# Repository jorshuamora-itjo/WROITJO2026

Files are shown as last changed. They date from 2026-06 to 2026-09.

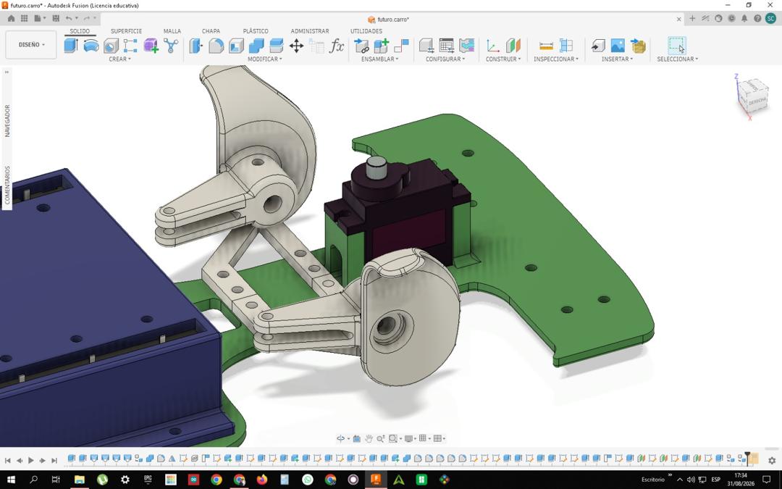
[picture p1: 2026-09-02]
photos/assembly_process/WhatsApp Image 2026-09-02 at 2.11.04 AM (2).jpeg

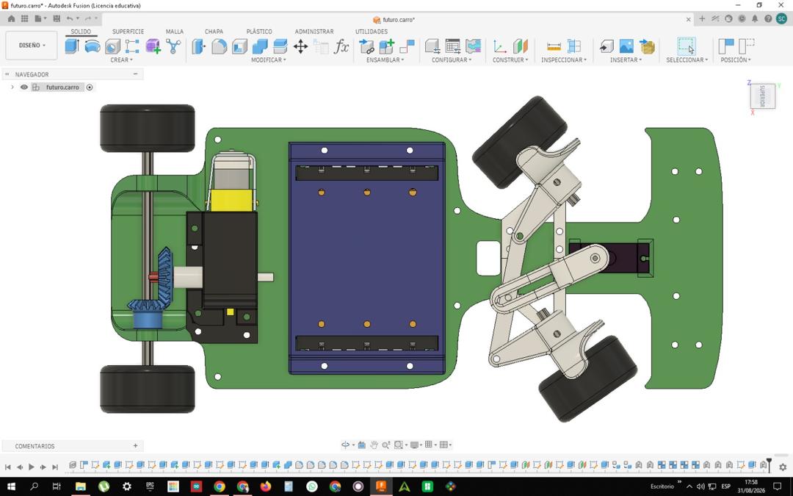
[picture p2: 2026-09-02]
photos/assembly_process/WhatsApp Image 2026-09-02 at 2.11.29 AM (2).jpeg

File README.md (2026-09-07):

<div align="center">

# WRO 2026 — Future Engineers
### **Team:** The Pits JO &nbsp;|&nbsp; **Robot:** Meteoro
**Instituto Técnico Jesús Obrero (ITJO)**






---

> 🇪🇸 **Nota para jueces y evaluadores en español:** Puedes leer la versión oficial traducida al español directamente en [`README_ES.md`](https://github.com/jorshuamora-itjo/WROITJO2026/blob/main/README.md#wro-2026--futuros-ingenieros).

---

</div>

## Engineering Materials

This repository contains all engineering materials, CAD models, schematic diagrams, source code, and technical documentation for the **Meteoro** autonomous vehicle, developed by team **The Pits JO** from **Jesús Obrero Technical Institute (ITJO)** for the **WRO Future Engineers 2026** competition.

### Repository Contents

* **[`README.md`](https://github.com/jorshuamora-itjo/WROITJO2026/blob/main/README.md#wro-2026--future-engineers)**: Main technical documentation in English.
* **[`README_ES.md`](https://github.com/jorshuamora-itjo/WROITJO2026/blob/main/README.md#wro-2026--futuros-ingenieros)**: Full technical documentation in Spanish.
* **[`LICENSE`](LICENSE)**: MIT open-source license corresponding to team The Pits JO.
* **[`.gitignore`](.gitignore)**: Configuration file to ignore build binaries and temporary files.
* **[`src/`](src/)**: Control software code for all components programmed for the competition.
* **[`models/`](models/)**: Files for models used by 3D printers, laser cutters, and CNC machines to manufacture vehicle parts.
* **[`photos/`](photos/)**: Unified photo gallery containing official team photos, vehicle views, and assembly/programming logs.
* **[`video/`](video/)**: File containing the direct link to the track demonstration video.
* **[`schematics/`](schematics/)**: Schematic diagrams of electromechanical components, illustrating all parts (electronic components and motors) used in the vehicle and how they connect.
* **[`docs/`](docs/)**: Additional documentation, datasheets, flow charts, and pit checklists.

---

> **Technical Nomenclature Clarification**
> 
> To facilitate reading the documentation and avoid confusion throughout this project, we use the following standard:
> 1. **Pit Dinoco (Version 1.1):** Our first experimental car. With it, we learned the fundamentals of the competition and identified the main flaws to correct.
> 2. **Meteoro (Version 2.0):** The definitive competition vehicle. It stems from a complete redesign of the mechanical structure, power circuits, and control software.

---

## Visual Comparison of Prototypes

| Design Criterion | Pit Dinoco ($v1.1$) | Meteoro ($v2.0$) |
| :--- | :--- | :--- |
| **Structure** | Single deck (monolayer) with exposed cables. | Double-deck modular chassis with internal cable routing channels. |
| **Steering** | Simple steering with servo exposed to wear. | Ackermann geometry with a Scotch Yoke mechanism. |
| **Drivetrain** | Visible spur gears. | Longitudinal motor with 90° bevel gears. |
| **Weight Distribution** | Batteries in the rear (caused understeer). | Batteries at the center of the lower chassis (50/50 balance). |
| **Distance Sensors** | HC-SR04 modules glued to the front. | RCWL-1601 sensors integrated inside the F1 front wing. |

---

## Introduction

The team **The Pits JO** consists of 6th-year Technical High School students from **Instituto Técnico Jesús Obrero (ITJO)**. Our academic background covers the fields of Electronics and Telematics, which provided us with the necessary tools to build an autonomous car from scratch.

Although in daily workshop practice we apply the philosophy of *"everyone does everything"* (assembling, soldering, programming, and track testing), we distribute primary responsibilities according to each member's specialty:

| Team Member | Academic Major | Primary Roles | Key Contributions and Cross-Functional Tasks |
| :--- | :--- | :--- | :--- |
| **Samuel Castillo** | Industrial Professional Technician in Electronics | 3D Mechanical Designer, Maintenance, and Electromechanical Integration | Designed the 3D parts and chassis for the  $v1.1$  and  $v2.0$  prototypes, calibrated the steering system, manufactured custom gears, and supported motor testing routines. |
| **Jorshua Mora** | Industrial Professional Technician in Telematics | Lead Software Programmer, Vision Specialist, and Pit Crew | Developed the core code, configured the PixyCam2 vision sensor, managed rapid maintenance in the competition pit area, and assisted with wiring harness assembly. |
| **Winston Garrido** | Industrial Professional Technician in Electronics | PID Control Algorithms, Schematic Designer, and Repository Manager | Calibrated the $PD$ trajectory control system, designed the power distribution network, drew schematic diagrams, and organized all technical documentation on GitHub. |

> **Note on Technical Guidance**  
> Per the recommendation and explicit request of our technical mentor, the architectural structure of the code and the steering geometry underwent rigorous track repeatability testing before being approved and installed on the Meteoro ($v2.0$) prototype.

---

## Diagnosis of Prototype v1.1 ("Pit Dinoco") and Lessons Learned

Upon completing our first competition run with Pit Dinoco, we conducted a detailed behavioral analysis to understand why it committed errors on the track. This analysis revealed four key mechanical and electrical flaws:

* **Exposed and Bent Cables:** Lacking an organized cable path, wires rubbed against moving parts or bent excessively, causing unexpected failures or loose connections.
* **Unbalanced Weight Distribution:** The lithium batteries were positioned at the rear of the car. This made the front end too light, losing grip and causing the car to "push wide" (understeer) in tight 90° turns.
* **Sensor Interference with Wheels:** The ultrasonic sensors were mounted too close to the front wheels. When the steering servo reached full lock, the wheels physically struck the sensors.
* **Steering Wear and Tear:** The mechanical linkage connected to the steering servo was flat and made of basic plastic. Continuous use and frictional heat softened and stripped the plastic, resulting in loss of center alignment.

### New Architectural Design Principles for "Meteoro" (v2.0)

Building upon the lessons learned from Pit Dinoco, we established four core pillars for constructing Meteoro:

1. **Ease of Maintenance:** Design a system where batteries can be swapped or control boards inspected without disassembling the entire vehicle on the workbench.
2. **Electrical Organization and Protection:** Implement internal routing channels to guide wiring and keep power supply cables separate from data/signal lines.
3. **Mechanical Resilience:** 3D print high-impact components using durable infill patterns (20% Gyroid with 5 wall perimeters) to withstand vibrations and potential collisions.
4. **Precise Steering:** Adopt an F1-style steering system driven by Ackermann geometry and a Scotch Yoke mechanism.

---

## Technical Inspirations and Engineering Changes

We retained the combination that yielded excellent durability results: a 3D-printed main chassis (PLA+/PETG) and standard electronics.

We replaced the traditional HC-SR04 sensors with the **RCWL-1601** model. Although they share identical pinouts (`VCC`, `TRIG`, `ECHO`, and `GND`), this new model offers distinct advantages in form factor and accuracy:

| Technical Parameter | Previous Module: HC-SR04 | Current Module: RCWL-1601 | Impact on the Meteoro Vehicle |
| :--- | :--- | :--- | :--- |
| **Dimensions** | Standard (45 mm  $\times$  20 mm) | Compact (21 mm  $\times$  18 mm) | Allows embedding all three sensors inside the front wing. |
| **Operating Voltage** | Rigid 5.0V DC | 3.0V to 5.5V DC | Withstands minor voltage fluctuations without failure. |
| **Field of View** | $\approx 15^\circ$ (prone to echoes) | $< 12^\circ$ (narrow beam) | Prevents false readings from sound bouncing off diagonal walls. |
| **Measurement Accuracy** | $\pm 3\text{ mm}$ | $\pm 1\text{ mm}$ | Provides stable measurement data to smoothly correct trajectory. |

### Integration of the F1 Front Wing

To improve cornering response time, we studied solutions applied by international WRO teams, drawing inspiration from the sensor layout of team **GammaVersion** (WRO Spain Champions).

* **Kinematic Advantage:** By mounting the sensors ahead of the front wheel axis, the vehicle "sees" walls with spatial anticipation before physically entering the turn.
* **Impact Protection:** We designed rigid plastic housings with a 0.1 mm clearance tolerance to protect sensor capsules against wall scrapes.
* **Spatial Orientation:** To keep the vehicle within maximum allowed dimensions (30 cm  $\times$  20 cm), side sensors are mounted vertically while the front sensor is positioned horizontally.

---

## Mechanical Specifications and Blueprints

Before 3D modeling, we drew full-scale blueprints on graph paper to ensure the car complied with competition rules:

* **Total Length:** 26 cm (Maximum allowed limit: 30 cm)
* **Total Width:** 13 cm (Maximum allowed limit: 20 cm)
* **Wheel Diameter:** 40 mm (Width: 20 mm)

### Drivetrain Re-engineering: Custom 3D Bevel Gears

By relocating the batteries to the center of the lower deck, we had to mount the DC motor longitudinally (parallel to the chassis). Since commercial off-the-shelf parts did not provide the exact gear ratio required, we designed and 3D printed a custom set of **90° bevel gears**:

$$\text{Gear Ratio} = \frac{\text{Driven Gear Teeth}}{\text{Drive Gear Teeth}} = \frac{24}{16} = 1.5$$

This  $1:1.5$  ratio provides the ideal balance between launch acceleration and top speed to propel our car's weight of  $\approx 660\text{ g}$.

---

## Ackermann Steering Mechanism and Axle Convergence

To prevent the front tires from scrubbing or slipping when taking 90° corners, we implemented Ackermann steering geometry driven by an **AD002** servo motor via a pin-guided mechanism (based on the Scotch Yoke).

**Ideal Kinematic Condition:**

$$\cot(\theta_{\text{ext}}) - \cot(\theta_{\text{int}}) = \frac{w}{L}$$

Where  $w = 128\text{ mm}$ (front track width) and  $L = 165\text{ mm}$ (wheelbase between front and rear axles).

**Track Steering Setup:**

We calibrated the steering convergence point 2.5 cm behind the rear axle. This provides optimal handling characteristics:

* **On Straightaways:** The vehicle tracks straight without sharp jerks or weaving.
* **In Turns:** The inner wheel ($\theta_{\text{int}}$) turns at a steeper angle than the outer wheel ($\theta_{\text{ext}}$), executing a clean turn without excessive friction.

---

## Double-Deck Structure and Wiring Routing

Meteoro is divided into two independent levels:

* **Lower Deck (Mechanical Base and Power):** Houses the centered 3S Li-ion battery pack, the drive motor with its 90° gearing, the servo-steered front assembly, and the F1 front wing. It also features a bottom hatch for swapping batteries in seconds.
* **Upper Deck (Logic Control and Vision):** Holds the L298N motor driver, the PixyCam2 camera, and the dual Arduino Nano microcontrollers (Master and Slave). Its enclosure shields the servo motor and keeps all wiring neatly routed through channels.

---

## Navigation Strategy for Meteoro

Meteoro's navigation strategy utilizes a closed-loop monitoring control architecture divided into three core pillars: sensor acquisition and EMA filtering, a Finite State Machine (FSM), and real-time controllers.

### Finite State Machine (FSM) Algorithm Definition

#### RECTA State (Adaptive PD Centering)
On straightaways, the vehicle aims to maintain an equal distance relative to the left and right side walls:

$$e(t) = \frac{\text{US}_{\text{right}} - \text{US}_{\text{left}}}{2}$$

To prevent oscillation or sudden over-corrections caused by small imperfections in the acrylic walls, a **Deadband** of  $\pm 5.0\text{ cm}$  is applied:

* If $|e(t)| \le 5.0\text{ cm} \implies \text{error} = 0$
* If $e(t) > 5.0\text{ cm} \implies \text{error} = e(t) - 5.0$
* If $e(t) < -5.0\text{ cm} \implies \text{error} = e(t) + 5.0$

The final steering angle is computed via Proportional-Derivative (PD) control action:

$$\text{PD Output} = K_p \cdot \text{error} + K_d \cdot \frac{d e(t)}{dt}$$

$$\theta_{\text{steering}} = \theta_{\text{neutral}} + \text{PD Output}$$

Where  $\theta_{\text{neutral}} = 92^\circ$,  $K_p = 10.33$, and  $K_d = 14.0$.

---

#### CURVA State (MPU6050 Gyro-Assisted Turn)
When the front sensor detects a wall at a distance $\le 75.0\text{ cm}$, the FSM transitions to the **CURVA** state:

* **Track Direction Determination (First Corner):** If this is the first corner of the run ($\text{trackDirection} == 0$), side sensor readings are compared:
    * **If `US_left` > `US_right`:** Counter-clockwise direction (65° Steering Angle)
    * **If `US_left` ≤ `US_right`:** Clockwise direction (115° Steering Angle)
  
  This value is stored in  $\text{trackDirection}$ and locks the turn direction for all remaining corners on the circuit.

* **Accumulated Yaw Angle Calculation ($\theta_z$):** Based on the angular velocity measured along the Z-axis ($\omega_z$), the accumulated yaw angle is computed:

$$\theta_z(t) = \theta_z(t - \Delta t) + \left( \frac{\text{Raw Gyro Z} - \text{offset}_z}{131.0} \right) \cdot \Delta t$$

* **Exit Criterion:** The turn remains actively engaged until the absolute value of accumulated rotation meets the target threshold:

$$|\theta_z(t)| \ge \theta_{\text{target}} \quad (\theta_{\text{target}} = 72.0^\circ)$$

---

#### COOLDOWN State (Post-Turn Protection Delay)
Upon completing the  $72^\circ$  turn, the vehicle enters a stabilization period (**COOLDOWN**) for  $1200\text{ ms}$. During this window:

1. The derivative term memory is reset ($\text{previous error} = 0$).
2. Front sensor readings are temporarily ignored to prevent false triggers caused by rotational inertia or exiting side walls.
3. PD control resumes using side sensor measurements to stabilize trajectory before returning to the **RECTA** state.

---

### Sensor Data Filtering (Hybrid EMA Filter)

Ultrasonic sensors occasionally produce outliers or false  $0\text{ cm}$ readings due to acoustic reflections. To mitigate this, the algorithm implements a hybrid **EMA (Exponential Moving Average)** filter with an opening threshold:

```cpp
// If sensor detects open space (> 70 cm) or error (0 cm),
// respond instantly to avoid missing corner openings.
// In normal ranges (close walls), apply EMA smoothing with alpha = 0.4.

float filtrarEMA(float lecturaActual, float lecturaAnterior, float alpha = 0.4) {
    if (lecturaActual == 0 || lecturaActual > 70.0) {
        return lecturaActual; // Instant response for openings/errors
    }
    return (alpha * lecturaActual) + ((1.0 - alpha) * lecturaAnterior);
}
```

---

## Meteoro Navigation Strategy for Obstacle Challenge

To successfully complete the Obstacle Challenge, the Meteoro autonomous vehicle evolves its control system. Building upon lane centering via the PD algorithm and the Finite State Machine (FSM), we integrate a real-time computer vision system using the PixyCam 2 camera, which works in perfect synchronization with the MPU6050 inertial measurement unit.

We maintain our Master-Slave distributed processing architecture connected via the I2C bus at a frequency of 100 kHz. In this way, the Master microcontroller assumes the responsibility of image processing and executing the decision-making logic, while the Slave is dedicated exclusively to actuating the Ackermann steering and the H-bridge traction motor.

---

### 1. Visual Perception and Anti-False Positive Filter

The PixyCam 2 is responsible for identifying and classifying circuit signals by recognizing two well-defined chromatic signatures:
* **Signature 1 (Green):** Indicates an obstacle that the vehicle must dodge by passing on the **LEFT**.
* **Signature 2 (Red):** Indicates an obstacle that must be dodged by passing on the **RIGHT**.

#### Proximity Filter and Debounce
In a competition environment, light reflections on the floor or distant flashes can generate erroneous readings. To avoid sudden maneuvers or false evasions, we implement a two-step validation:
1. **Filter by Vertical Dimension ($h$):** The system ignores any distant mark or visual noise. Only blocks whose height in pixels falls within the operational proximity range ($60\text{ px} \le h \le 240\text{ px}$) are considered valid.
2. **Temporal Frame Debounce:** We require the color signature to be detected uninterruptedly for at least 3 consecutive frames (`UMBRAL_CONFIRMACION = 3`). Only when this condition is met are the maneuver flags (`verdeConfirmado` or `rojaConfirmada`) activated.

---

### 2. Finite State Machine (FSM) and Priority Hierarchy

The Master microcontroller's state machine (`EstadoEsquive`) organizes the car's behavior under a strict hierarchical structure. This avoids conflicts when vision, ultrasound, or inertial orientation readings coincide:

#### Decision Priority Matrix

| Priority | Activation Condition | Activated State | Main Action |
| :---: | :--- | :--- | :--- |
| **1 (Highest)** | `verdeConfirmado` or `rojaConfirmada` | `ESQUIVANDO_IZQ` / `DER` | Immediately initiates the inertial dodge sequence. |
| **2 (Medium)** | $d_{\text{front}} \le 90\text{ cm}$ and open side space | `GIRANDO_CURVA` | Executes an inertial turn of 63° towards the opening. |
| **3 (Base)** | No obstacles or pending turns | `RECTA_NORMAL` | Centers the car in the lane using PD control ($\text{Zona Azul} = \pm 3.5\text{ cm}$). |

---

### 3. 3-Phase Dodge Algorithm (Closed Inertial Control)

Instead of basing invasive maneuvers on fixed timers—which fail when tire grip changes or battery charge drops—Meteoro utilizes orientation measurements from the MPU6050 gyroscope. This ensures precise lane changing and re-entry in a trajectory parallel to the track.

#### Evasive Sequence for Green Obstacle (Passing on the Left)

1. **Phase 1: Diagonal Deviation (`ESQUIVANDO_IZQ`):**
   * **Steering:** The servo is set to 125° (steering wheel turned to the right).
   * **Transition criterion:** The gyroscope integrates angular velocity until registering a net rotation of $\theta_z \ge +10.0^\circ$ (or until the visual mark passes the coordinate $x \ge 220\text{ px}$).

2. **Phase 2: Parallel Overtake (`REBASANDO_IZQ`):**
   * **Steering:** Steering is centered to exactly 90°.
   * **Transition criterion:** The car advances straight in the opposite lane to overtake the obstacle for $t_{\text{rebase}} = 600\text{ ms}$.

3. **Phase 3: Straightening and Re-entry (`ENDEREZANDO_IZQ`):**
   * **Steering:** Counter-steering is applied with steering set to 45°.
   * **Transition criterion:** Gyroscope readings are monitored until cumulative inclination returns to $\theta_z \le 0.0^\circ$ (canceling initial inclination), or a maximum protection time of 200 ms elapses. Upon completion, the system smoothly returns to the `RECTA_NORMAL` state.

> **Note:** The maneuver to dodge the Red Obstacle applies an inverse symmetrical geometry: initial turn at 35° until reaching $\theta_z \le -10.0^\circ$, centered forward motion at 90° for 600 ms, and straightening counter-steer at 135°.

---

### 4. Adaptive Corner Detection ("Side Gap")

To prevent the car from confusing a nearby corner wall with an obstacle it needs to dodge, the algorithm intelligently combines information from the PixyCam and the three ultrasonic sensors:

1. **Camera Memory Immunity:** If the camera detected any chromatic mark during the last second (`millis() - ultimoTiempoBloque < 1000 ms`), track turn activation is automatically disabled.
2. **Open Path Criterion ("Side Gap"):** The system detects arrival at a corner by evaluating the sudden opening of a side wall ($d_{\text{izq}} > 90\text{ cm}$ or $d_{\text{der}} > 90\text{ cm}$) combined with the presence of the front wall within approach range ($55\text{ cm} < d_{\text{front}} \le 90\text{ cm}$).
3. **Confirmation and Curve Integration:** After confirming two consecutive valid readings (`UMBRAL_CURVA = 2`), the system enters the `GIRANDO_CURVA` state, setting the steering to 35° or 145° depending on the side of the detected gap. The turn is actively maintained until the MPU6050 counts a real turn of $\theta_z = 63.0^\circ$.
4. **Exit Protection (`COOLDOWN_CURVA`):** Once the curve is completed, the servo is centered for 200 ms to stabilize travel, and a temporary block of 2000 ms (`FRONT_COOLDOWN_CURVA`) is activated to prevent registering false turns with the exit wall.

---

### 5. Communication and I2C Distributed Architecture

To avoid delays in the PD control calculation cycle caused by the processing time of the camera and ultrasonic readings, the physical execution of the motors is completely separated into the Slave microcontroller:
* **Message Transmission:** The Master generates and transmits lightweight 2-byte packets in the format: `[target_angle, current_speed]`.
* **Interrupt Processing:** The Slave receives commands via the `Wire.onReceive()` routine, storing values in variables declared as `volatile`. This guarantees that the physical update of the servo angle and motor power occurs in the main loop immediately, cleanly, and safely.

---

## Mechanical Design and Evolution

### Post-Mortem Diagnosis and Mechanical Challenges in Pit Dinoco (v1.1)

Performance analysis during our first track competition provided us with the real diagnosis that we could not fully observe during workshop testing. We identified four key mechanical and physical distribution issues:

* **Wiring Organization and Lack of Space:** In an attempt to minimize dimensions on a single layer (single deck), we overcrowded the central area. Signal cables were left exposed to constant friction with moving engine and transmission parts, leading to intermittent failures due to wire wear.
* **Center of Gravity (CG) Imbalance:** Positioning the lithium batteries at the rear shifted the center of gravity away from its ideal balance point. This lack of weight over the front wheels reduced ground traction, resulting in noticeable front-end push (understeer) during 90° turns.
* **Physical Obstruction in Steering:** The front ultrasonic sensors collided directly with the wheels at full lock, limiting the vehicle's turning angle.
* **Steering Arm Wear and Tear:** The original servo arm (3D printed and manually fitted in plastic) failed under continuous use. Constant friction generated heat, eventually stripping the gear teeth and misaligning the steering's neutral point.

---

### Mechanical Architecture Comparison: v1.1 vs v2.0

We retained the combination of materials that yielded solid results: integrating 3D-printed parts (PLA+/PETG) and standard electronic components.

However, to address structural weaknesses, we completely redesigned the chassis. The table below details the implemented improvements:

| Constructive Criterion | Initial Prototype: Pit Dinoco (v1.1) | Competitive Prototype: Meteoro (v2.0) | Mechanical and Dynamic Impact |
| :--- | :--- | :--- | :--- |
| **Chassis Distribution** | Single flat layer with exposed components. | Interconnected modular double deck. | Separates the power stage from control electronics and protects components. |
| **Steering Geometry** | Direct central pivot (symmetrical turn). | Ackermann geometry driven by a Scotch Yoke. | Eliminates unwanted tire scrubbing in tight corners. |
| **Rear Drivetrain** | Exposed spur gears on the same plane. | 3D-printed 90° bevel gears. | Allows mounting the motor longitudinally along the chassis, freeing internal space. |
| **Battery Location** | Positioned at the rear (behind the axle). | Centered lower compartment (between both axles). | Balances the center of gravity (50/50) and eliminates front-end understeer. |
| **Sensor Mounting** | Independent brackets beside the wheels. | F1-style front wing with collision protection. | Improves reading anticipation and shields sensors from impacts. |
| **Pit Maintenance** | Complete disassembly required for any change. | Quick-access hatch on the lower deck. | Allows swapping batteries in seconds without touching the electronics. |

---

### Mechanical Re-engineering in Meteoro (v2.0)

#### 1. Integrated F1 Front Wing ("GammaVersion" Inspiration)
Drawing inspiration from the sensor distribution of team **GammaVersion** in WRO, we designed an F1-style front wing structure via 3D printing:

* **Anticipated Readings:** Positioning the three ultrasonic sensors ahead of the front axle allows the system to detect walls with greater anticipation before the vehicle's body enters the turn.
* **Collision Protection:** Sensors snap firmly into rigid housings with a precise 0.1 mm clearance, doubling as a protective bumper.
* **Efficient Layout:** Side sensors are mounted vertically while the central sensor is horizontal to stay within the maximum allowed dimensions of 30 cm × 20 cm.

---

#### 2. Ackermann Steering Geometry
We replaced the simple pivot with an Ackermann geometric steering system driven by a metal-geared **AD002** servo motor, connected via a slotted guide pin mechanism (Scotch Yoke).

$$\cot(\theta_{\text{ext}}) - \cot(\theta_{\text{int}}) = \frac{w}{L}$$

Where  $w = 128\text{ mm}$ (front track width) and  $L = 165\text{ mm}$ (wheelbase).

This configuration forces the inner wheel ($\theta_{\text{int}}$) to turn at a steeper angle than the outer wheel ($\theta_{\text{ext}}$), allowing both to follow the natural cornering arc without scrubbing.

* **Stability Calibration:** We tuned the geometry so that the alignment convergence point sits 2.5 cm behind the center of the rear axle. This keeps the vehicle firm and stable on straightaways without sacrificing agility in 90° turns.

---

#### 3. Redesigned Drivetrain: Custom 90° Bevel Gears
To place the batteries in the center of the lower deck, we oriented the motor longitudinally along the chassis. Also we designed and 3D printed a custom pair of **90° bevel gears**:

$$\text{Gear Ratio} = \frac{\text{Driven Teeth}}{\text{Drive Teeth}} = \frac{24}{16} = 1.5$$

This 1:1.5 ratio offers the ideal balance between launch torque and top speed for the vehicle's total weight (660 g).

---

#### 4. Double-Deck Modular Distribution
Meteoro's structure simplifies inspections and repairs by organizing into two levels:

* **Lower Deck (Drivetrain and Power):** Houses the centered 3S Li-ion battery pack, the main motor with its bevel gears, the metal steering servo, and the front wing. Includes a quick-access bottom hatch for swapping batteries conveniently.
* **Upper Deck (Control and Sensors):** Holds microcontrollers, the L298N motor driver, the PixyCam2 camera, and internal routing channels that keep signal cables isolated from power lines.

---

#### 5. Dimensional Verification
Before final CAD modeling, we drafted dimensions on graph paper to guarantee compliance with WRO regulations (30 cm × 20 cm):

* **Total Length:** 260 mm
* **Total Width:** 130 mm
* **Wheel Diameter:** 40 mm (Width: 20 mm)

---

## Electronic Architecture and Power System

In autonomous robotics, software stability depends entirely on the reliability of the underlying electrical system. On our first prototype (Pit Dinoco), we suffered unexpected microcontroller resets due to power interference generated by the main motor and instantaneous current draws from the steering motor.

For Meteoro (v2.0), we completely redesigned the electronic architecture by splitting workload across two networked microcontrollers and constructing isolated, independent power circuits for each system requirement.

---

### Distributed Logic Architecture (Master / Slave via I2C)

To avoid delays in sending motor commands while simultaneously reading sensors, we divided tasks between two Arduino Nano boards interconnected via the I2C data bus (at address `0x08`):

* **Arduino Nano Master:** Functions as the vehicle's "brain." It reads distances from the three ultrasonic sensors, calculates tilt/heading using the MPU6050 gyroscope, performs color recognition with the PixyCam2 camera (connected via SPI bus), and processes mathematical control equations to guide the car.
* **Arduino Nano Slave:** Acts as the system's "muscle." It rapidly receives commands sent by the Master and directly drives the steering servo motor and the L298N driver that powers the main motor.

---

### Pinout Map

To inspect complete, illustrated graphic schematics, please refer to the `schematics/` folder in the repository.

#### Pin Mapping - Arduino Nano Master

| Module / Component | Component Pin | Arduino Nano Pin | Signal Type | Logic Level | System Function |
| :--- | :--- | :--- | :--- | :--- | :--- |
| **Left Ultrasonic** | ECHO | D6 | Input | 5.0 V | Echo reception for left wall |
| | TRIG | D7 | Output | 5.0 V | Ultrasonic pulse emission |
| **Right Ultrasonic** | ECHO | D8 | Input | 5.0 V | Echo reception for right wall |
| | TRIG | D9 | Output | 5.0 V | Ultrasonic pulse emission |
| **Front Ultrasonic** | ECHO | D10 | Input | 5.0 V | Echo reception for corner detection |
| | TRIG | D11 | Output | 5.0 V | Ultrasonic pulse emission |
| **Gyroscope (MPU6050)** | SDA | A4 | I2C Data | 5.0 V | Z-axis rotation reading |
| | SCL | A5 | I2C Clock | 5.0 V | Synchronization clock (100 kHz) |
| **I2C Interconnect (Slave)** | SDA | A4 | I2C Data | 5.0 V | Sends steering and speed commands |
| | SCL | A5 | I2C Clock | 5.0 V | Shared clock channel |
| **PixyCam2 Camera** | MOSI / MISO / SCK | D11 / D12 / D13 | SPI Bus | 5.0 V | Visual recognition at 60 frames per second |
| **Logic Power** | 5V / GND | 5V / GND | Power | 5.0 V Reg. | Input from Regulator Channel 1 |

---

#### Pin Mapping - Arduino Nano Slave

| Module / Component | Component Pin | Arduino Nano Pin | Signal Type | Logic Level | System Function |
| :--- | :--- | :--- | :--- | :--- | :--- |
| **AD002 Steering Servo** | Signal (PWM) | D2 | PWM Output | 5.0 V | Angle adjustment for Ackermann steering |
| **L298N Driver (DC Motor)** | IN1 / A1 | D5 | PWM Output | 5.0 V | Speed control for traction |
| | IN2 / A2 | D6 | Digital Output | 5.0 V | Direction of travel (LOW for forward) |
| **I2C Interconnect (Master)** | SDA | A4 | I2C Data | 5.0 V | Receives commands from Master |
| | SCL | A5 | I2C Clock | 5.0 V | Shared clock channel |
| **Logic Power** | 5V / GND | 5V / GND | Power | 5.0 V Reg. | Input from Regulator Channel 2 |

---

### Power Distribution Network and Regulation

The primary power source consists of a 3-cell series lithium battery pack (3S) delivering a nominal voltage of 11.1 V (reaching 12.6 V fully charged).

To completely eliminate voltage drops that triggered system resets, we split current distribution using two independent buck voltage regulators (DSN-MINI-360 Buck modules):

| Power Stage | Input Source | Regulated Output | Powered Components |
| :--- | :--- | :--- | :--- |
| **Lithium Batteries (3S)** | 3 × 3.7 V Pack | 11.1 V - 12.6 V Direct | Power input for main motor (L298N Driver) |
| **Buck Regulator 1 (Channel 1)** | 3S Lithium Pack | 5.0 V DC Regulated | Arduino Nano Master, MPU6050 Gyro, 3 Ultrasonic Sensors, and PixyCam2 |
| **Buck Regulator 2 (Channel 2)** | 3S Lithium Pack | 5.0 V DC Regulated | Arduino Nano Slave and AD002 Steering Servo |
| **Common Ground (GND)** | N/A | 0 V | Joint ground connection for all boards and sensors |

---

### Power Isolation Benefits

* **Protection Against High Current Demands:** When the servo motor executes sharp turns in tight corners, it draws power exclusively from Channel 2. This prevents camera or processor supply voltage from dropping below the 4.5 V operational threshold.
* **Interference Filtering:** The traction motor receives direct power from the battery pack. The isolated buck regulators filter out current spikes and electrical noise generated by the L298N driver.
* **Common Ground Reference:** Despite separate voltage regulation, all ground wires (0 V / GND) tie into a single point to ensure clear, accurate data transmission across the I2C bus.

---

### Reference Electronic Schematics

Visual wiring guides are available in the repository's [`schematics/`](schematics/) folder:

* `schematics/nano_master_diagram.jpg`: Wiring diagram for the Master circuit (Sensors, Vision, I2C, and Power Channel 1).
* `schematics/nano_slave_diagram.jpg`: Wiring diagram for the Slave circuit (Motors, L298N Driver, Servo Motor, and Power Channel 2).
* `schematics/pinout_table.md`: Quick-reference document for connection verification during pit testing.

---

## Software Architecture and Control Logic

### Code Historical Evolution (v1 to v4)

Software development for our vehicle did not happen overnight. Facing the real track taught us that pure theory quickly breaks down when sensors bounce off open corners or when wheels chatter due to numerical noise. Below is the documented evolutionary process of our code revisions stored in the `src/history/` directory leading up to the current implementation in `src/current/`.

* **Version 1: Monolithic and Blocking (`src/history/v1_pid_control.ino`)**
  * **Architecture:** A single Arduino Uno executing all processing tasks sequentially.
  * **Mechanism:** Distance measurement using the `pulseIn()` function, which paused the processor for up to 12 ms per sensor. Reading 3 sensors caused the processor to freeze for over 35 ms per cycle.
  * **Critical Failure:** Upon reaching a corner, the front sensor lost wall detection or read false reflections. The PID algorithm attempted to correct non-existent distances, resulting in abrupt steering maneuvers and collisions with the outer wall.

* **Version 2: State Transition (`src/history/v2_pid_switch.ino`)**
  * **Innovation:** Implemented a Finite State Machine (`RECTA` and `CURVA`) for the first time to decouple lane-centering control from cornering maneuvers.
  * **Control:** Automatic speed reduction upon detecting an approaching wall (set to 80% of maximum speed).
  * **Critical Failure:** The vehicle returned to the `RECTA` state before fully exiting the corner. Detecting the side wall too close immediately after turning, the PID applied an instantaneous counter-steering jerk.

* **Version 3: Timers and Cooldown (`src/history/v3_fsm_cooldown.ino`)**
  * **Innovation:** Introduced the `COOLDOWN_CURVA` constant (1500 ms) to prevent the vehicle from re-entering the turn state immediately after exiting one.
  * **Steering:** First version to record whether the open wall was to the left or right before initiating the fixed maneuver.
  * **Critical Failure:** Relying on fixed duration timings (`DURACION_GIRO = 2500 ms`) caused derailments when battery charge dropped: at lower voltage, the vehicle covered less distance in the same time window, leaving it oriented diagonally.

* **Version 4: Median Filter and Gap Detection (`src/history/v4_median_filter.ino`)**
  * **Innovation:** Incorporated a median filter over 4-sample arrays (`filtroMediana4`) to reject noise spikes caused by wall textures.
  * **Logic:** Detection of lane openings when measured distance exceeded the `distanciaHueco` threshold (90 cm).
  * **Breakthrough Point:** Although the median filter cleaned the signal, array sorting calculations consumed noticeable processor cycles. Furthermore, the vehicle still lacked absolute certainty regarding its rotational angle about its vertical axis.

---

### Software Evolution Comparison Table

| Logic / Performance Criterion | v1 (Monolithic) | v2 (Simple States) | v3 (Cooldown) | v4 (Median Filter) | Current Version (`src/current/`) |
| :--- | :--- | :--- | :--- | :--- | :--- |
| **Processor** | 1 Arduino Uno | 1 Arduino Uno | 1 Arduino Uno | 1 Arduino Uno | 2 Arduino Nano (I2C) |
| **Ultrasonic Reading** | Blocking `pulseIn()` | Direct `pulseIn()` | Timed `pulseIn()` | Median (4 samples) | NewPing Library + EMA |
| **Turn Detection** | Wall distance | Fixed front threshold | Distance + Time | Gap Detection | Integrated MPU6050 Gyroscope |
| **Noise Filtering** | None (Raw) | Rigid threshold | Rigid threshold | 4-point Median Filter | EMA ($\alpha = 0.4$) + 180 cm Limit |
| **Direction Safety** | Non-existent | Instant reactive | Event lockout | Character memory | Permanent `sentidoPista` (EEPROM/RAM) |

---

### Distributed Network Architecture (Master / Slave)

To guarantee a constant cycle time ($\Delta t$) free of execution delays during motor control signal generation, the current codebase located in `src/current/` divides computational load across two processors communicating over the I2C bus at 100 kHz.

#### Slave Code Analysis for the Open Challenge (`src/current/nano_slave.cpp`)

The Slave microcontroller acts as a dedicated peripheral controller exclusively managing the physical movement of steering and traction, keeping logic execution isolated from sensor-related timing delays.

##### 1. Interrupts and Safe Buffer
To prevent data corruption while executing motor commands, incoming data received via the `Wire.onReceive(recibirDatosI2C)` event handler is stored in protected variables qualified with the `volatile` keyword:

```cpp
volatile byte anguloRecibido = 90;
volatile byte velRecibida = 255;
volatile bool actualizarMotores = false;
```

The function handling incoming data simply captures transmitted values and sets a flag signal, allowing physical motor activation to occur within the main loop (`loop()`) to avoid freezing I2C communication:

```cpp
void recibirDatosI2C(int cuantosBytes) {
  if (cuantosBytes >= 2) {
    anguloRecibido = Wire.read();    
    velRecibida = Wire.read(); 
    actualizarMotores = true; // Notifies main loop
  }
}
```

##### 2. Progressive Launch Algorithm (`arrancarSuave`)
When launching the car from rest, the electric motor demands an initial current peak (*inrush current*) that can cause electrical noise on the power supply line. The slave firmware prevents this by stepping up speed incrementally over microseconds:

```cpp
void arrancarSuave() {
  digitalWrite(pinB, LOW);
  for (int vel = 0; vel <= velRecibida; vel++) {
    analogWrite(pinA, vel);
    delayMicroseconds(3921); // Acceleration ramp ~1 second total
  }
}
```

### Master Code Analysis for the Open Challenge (`src/current/nano_master.cpp`)

The Master microcontroller serves as the primary brain: it analyzes surroundings via sensors, measures car turns, manages mode changes, and computes the adjustments required to maintain the ideal path.

---

#### Digital Filtering: Exponential Moving Average (EMA)

To eliminate wheel chatter on straightaways without overloading the processor with complex list-sorting routines, we implemented a data smoothing filter (EMA).

**Mathematical Formulation:**
$$y[k] = \alpha \cdot x[k] + (1 - \alpha) \cdot y[k-1]$$

Where:
* $x[k]$ represents the raw reading obtained by the sensor at current time step $k$.
* $y[k-1]$ is the filtered distance calculated in the previous iteration.
* $\alpha = 0.4$ is the smoothing factor configured through practical testing.

**Spatial Zero Handling (0 cm = 180 cm):**
When the wall disappears at an intersection, the ultrasonic sensors return a value of 0 cm due to echo loss. We interpret this as completely open space by assigning it a theoretical distance of 180.0 cm, avoiding division-by-zero errors or false corrections:

```cpp
float filtrarLectura(float lecturaCruda, float lecturaAnterior) {
  float lecturaProcesada = lecturaCruda;
  if (lecturaCruda <= 0.0) {
    lecturaProcesada = 180.0; // Open space at corner
  }

  // If open space is detected (> 70 cm), allow fast response
  if (lecturaProcesada > 70.0) {
    return lecturaProcesada; 
  }

  // EMA smoothing for fine navigation near walls
  float alpha = 0.4;
  return (alpha * lecturaProcesada) + ((1.0 - alpha) * lecturaAnterior);
}
```

### MPU6050 Gyroscope Inertial Integration

Unlike previous versions, turns in the current version do not rely on bouncing waves off non-existent walls. We calculate rotation by continuously integrating the angular velocity ($\omega_z$) measured by the MPU6050 motion sensor over the I2C connection (address `0x68`):

**Rotation Angle Calculation:**
$$\theta_z = \sum \left( \frac{\text{giroZ}}{131.0} \right) \cdot \Delta t$$

Where the value 131.0 LSB/(°/s) corresponds to the sensitivity scale of ±250°/s configured on the MPU6050 sensor.

```cpp
// In the loop inside CURVA state
float giroZ = (leerGiroscopioZ() - offsetZ) / 131.0; 
anguloZ_acumulado += (giroZ * dt);

if (abs(anguloZ_acumulado) >= ANGULO_OBJETIVO) { // ANGULO_OBJETIVO = 72.0°
  estadoActual = COOLDOWN;
  tiempoInicioCooldown = millis();
}
```

### Finite State Machine and Track Logic

* **Track Direction Memory (`sentidoPista`):** During the first turn of the run (`sentidoPista == 0`), the vehicle analyzes which side offers a larger opening and permanently records the circuit direction. Once assigned, the remaining 11 corners of the run read directly from `sentidoPista`, ignoring erroneous readings caused by acoustic reflections.

#### PD Controller with Deadband (Blue Zone)

In `RECTA` mode, the vehicle stays centered between both walls by measuring the centering difference $e(t)$:

$$e(t) = \frac{\text{distRight} - \text{distLeft}}{2}$$

**Blue Zone Filter (±5 cm):**
To prevent unnecessary corrections caused by wall imperfections or textures on the track, a deadband of ±5 cm is applied:

```cpp
const float ZONA_AZUL = 5.0; 
float error = 0; 

if (abs(distancia_al_centro) <= ZONA_AZUL) {
  error = 0; 
}
else {
  if (distancia_al_centro > 0) error = distancia_al_centro - ZONA_AZUL; 
  else error = distancia_al_centro + ZONA_AZUL;
}
```

**Proportional-Derivative Equation:**
$$u(t) = K_p \cdot e(t) + K_d \cdot \frac{e(t) - e(t-\Delta t)}{\Delta t}$$

* **Proportional Gain ($K_p = 10.33$):** Responds to the magnitude of the vehicle's off-center offset.
* **Derivative Gain ($K_d = 14.0$):** Dampens lateral oscillation by predicting the velocity at which the car approaches the wall.
* **Strict Steering Limit:** The output $u(t)$ is bounded to ±15° around the steering servo's neutral point (92°), restricting the physical steering angle to a window between 57° and 127°.

---

### Analysis of the Slave Code for the Obstacle Challenge (`src/current/second_challenge/slave_nano.cpp`)

In Meteoro's architecture, the Slave microcontroller acts as a peripheral execution node. Its main responsibility is to abstract the physical generation of Pulse-Width Modulation (PWM) signals for traction and steering. In this way, I2C bus communication times are prevented from affecting the vehicle's dynamic performance and physical response.

---

#### 1. I2C Interrupt and Actuation Decoupling

To prevent locks in data reception and avoid register write inconsistencies while the microcontroller executes control instructions, incoming packets processed by the `Wire.onReceive(recibirDatosI2C)` function are stored in memory buffers protected by the `volatile` qualifier:

```cpp
volatile byte anguloRecibido = 90;
volatile byte velRecibida = 255;
volatile bool actualizarMotores = false;
```

The Interrupt Service Routine (ISR) validates the number of received bytes, extracts the angle and speed commands, and immediately activates a notification flag. This design guarantees that the routine returns control to the bus almost instantaneously:

```cpp
void recibirDatosI2C(int cuantosBytes) {
  if (cuantosBytes >= 2) {
    anguloRecibido = Wire.read();
    velRecibida = Wire.read();
    actualizarMotores = true; // Notifies the main loop
  }
}
```

#### 2. Asynchronous Open-Loop Execution

The main loop (`loop()`) constantly evaluates the `actualizarMotores` flag. When an update is detected, it immediately applies the new values to the physical actuators. This ensures that updating the servomotor (`miServo.write()`) and the H-bridge (`analogWrite()`) takes place outside the rigid context of the interrupt:

```cpp
void loop() {
  if (actualizarMotores) {
    miServo.write(anguloRecibido);
    analogWrite(pinA, velRecibida);
    digitalWrite(pinB, LOW);
    actualizarMotores = false; // Resets the notification signal
  }
}
```

---

### Analysis of the Master Code for the Obstacle Challenge (`src/current/second_challenge/master_nano.cpp`)

The Master microcontroller constitutes the central processing and decision-making unit. It coordinates real-time vision processing sent by the PixyCam 2 camera, ultrasonic distance fusion using the `NewPing` library, and angular orientation calculation via the MPU6050 gyroscope.

---

#### 1. Visual Perception and Anti-False Positive Filter (Debounce)

To avoid unwanted dodge maneuvers caused by track reflections or light flashes, the algorithm filters detected color signatures using a two-stage cascaded validation system:

#### A. Filter by Block Size ($h$)
The system discards any block whose height in pixels ($h$) does not fall within the operational proximity range. This ensures reaction only to real obstacles located at a relevant distance from the front bumper:

$$60\text{ px} \le h \le 240\text{ px}$$

#### B. Temporal Frame Confirmation Debounce
The algorithm requires a continuous presence of the same color signature across $N$ consecutive frames (`UMBRAL_CONFIRMACION = 3`). Only when this consistency is reached are the logical maneuver flags (`verdeConfirmado` or `rojaConfirmada`) activated:

```cpp
if (verdeEnFrame) {
  lecturasVerdeConsecutivas++;
  lecturasRojaConsecutivas = 0;
} else if (rojaEnFrame) {
  lecturasRojaConsecutivas++;
  lecturasVerdeConsecutivas = 0;
} else {
  lecturasVerdeConsecutivas = 0;
  lecturasRojaConsecutivas = 0;
}

bool verdeConfirmado = (lecturasVerdeConsecutivas >= UMBRAL_CONFIRMACION);
bool rojaConfirmada = (lecturasRojaConsecutivas >= UMBRAL_CONFIRMACION);
```

#### 2. Distance Filtering and Lost Echo Handling

Raw readings from the three ultrasonic sensors are processed using an Exponential Moving Average (EMA) filter to smooth out sudden variations. When the ultrasonic pulse does not return due to a wall opening (yielding a value of 0.0 cm in `NewPing`), the algorithm replaces the null value with the practical upper limit of the environment (200.0 cm). This controlled saturation prevents inconsistencies in control equations:

```cpp
float filtrarLectura(float lecturaCruda, float lecturaAnterior) {
  if (lecturaCruda == 0.0) {
    lecturaCruda = 200.0; // Saturation due to missing echo (open path)
  } else if (lecturaCruda <= 2.0) {
    return lecturaAnterior; // Noise rejection due to contact or vibration
  }

  float alpha = 0.4;
  return (alpha * lecturaCruda) + ((1.0 - alpha) * lecturaAnterior);
}
```

#### 3. Yaw Inertial Integration ($\theta_z$) with MPU6050

The orientation angle along the vertical axis ($\theta_z$) is calculated via continuous numerical integration of the angular velocity ($\omega_z$) captured from register `0x47` of the MPU6050 gyroscope via I2C:

$$\theta_z(k) = \theta_z(k-1) + \left( \frac{\text{giroZ} - \text{offsetZ}}{131.0} \right) \cdot \Delta t$$

Where the constant 131.0 LSB/(°/s) corresponds to the scale factor for the configured sensitivity of ±250°/s.

```cpp
float giroZ = (leerGiroscopioZ() - offsetZ) / 131.0;

if (estadoEsquive != RECTA_NORMAL) {
  anguloZ_acumulado += (giroZ * dt);
}
```

#### 4. Finite State Machine (FSM) with Priority Hierarchy

The Master's FSM organizes the overall behavior of the vehicle by establishing a strict decision hierarchy to resolve any conflict between the camera, ultrasonic sensors, and IMU:

* **Priority 1 (Highest):** Inertial obstacle dodging (`ESQUIVANDO_IZQ` / `ESQUIVANDO_DER`). Activated immediately upon confirming a chromatic signature.
* **Priority 2 (Medium):** Adaptive corner turning via lateral clearance (`GIRANDO_CURVA`). Activated when detecting the disappearance of a side wall alongside the approach of the front wall.
* **Priority 3 (Base):** Automatic lane centering via PD control (`RECTA_NORMAL`). Operates by default when no maneuvers or pending turns exist.

#### 5. Lane PD Control with Deadband (Blue Zone)

During the `RECTA_NORMAL` state, the vehicle maintains a centered trajectory by evaluating the lateral deviation error $e(t)$:

$$e(t) = \frac{d_{\text{der}} - d_{\text{izq}}}{2}$$

#### A. Blue Zone Filter (±3.5 cm)
To prevent unnecessary oscillations in the front wheels caused by small wall irregularities, the algorithm applies a deadband of ±3.5 cm:

```cpp
const float ZONA_AZUL = 3.5;

if (abs(distancia_al_centro) <= ZONA_AZUL) {
  error = 0;
} else {
  if (distancia_al_centro > 0) error = distancia_al_centro - ZONA_AZUL;
  else error = distancia_al_centro + ZONA_AZUL;
}
```

#### B. Control Equation and Output Bounding

Proportional and derivative action is applied. To avoid abrupt jumps in the servo, the rate of change of the derivative ($\frac{\Delta e}{\Delta t}$) is constrained, and the total correction $u(t)$ is bounded to a safe dynamic range:

$$u(t) = \text{constrain}\left( K_p \cdot e(t) + K_d \cdot \text{constrain}\left(\frac{e(t) - e(t-\Delta t)}{\Delta t}, -150, 150\right), -17, 17 \right)$$

$$\text{anguloDestino} = \text{constrain}\left( 90 + u(t), 45, 135 \right)$$

#### 6. 3-Phase Inertial Dodge Algorithm

Upon confirming a valid chromatic signature, the FSM executes a dodge sequence guided dynamically by the gyroscope's orientation:

#### Driving Sequence for Green Obstacle (Passing on the Left)

1. **Phase 1: Diagonal Deviation (`ESQUIVANDO_IZQ`):**
   * **Steering angle:** 125° (initial turn).
   * **Exit criterion:** Accumulated inclination is monitored until registering $\theta_z \ge +10.0^\circ$ (or until the visual centroid reaches $x \ge 220\text{ px}$).

2. **Phase 2: Parallel Overtake (`REBASANDO_IZQ`):**
   * **Steering angle:** 90° (centered steering).
   * **Exit criterion:** The car advances straight in the opposite lane to overtake the obstacle for a fixed interval of $t_{\text{rebase}} = 600\text{ ms}$.

3. **Phase 3: Straightening and Re-entry (`ENDEREZANDO_IZQ`):**
   * **Steering angle:** 45° (opposite counter-steer).
   * **Exit criterion:** Net inertial rotation cancels initial inclination ($\theta_z \le 0.0^\circ$) or safety limit time elapses ($t_{\text{ender}} = 200\text{ ms}$). Once the condition is met, the system cleanly returns to the `RECTA_NORMAL` state.

> **Note:** The evasive maneuver for the Red Obstacle executes an opposite symmetrical geometric pattern: initial angle at 35° until $\theta_z \le -10.0^\circ$, centered overtake at 90° for 600 ms, and straightening counter-steer at 135°.

#### 7. Adaptive Corner Detection ("Side Gap")

To turn at track intersections without confusing the corner wall with a colored obstacle, the program evaluates the opening of a side wall in combination with the proximity of the front wall:

```cpp
bool posibleObstaculo = (millis() - ultimoTiempoBloque < MEMORIA_PIXY_MS);
bool huecoIzquierda = (distIzqFiltrada > 90.0);
bool huecoDerecha = (distDerFiltrada > 90.0);

if (distFrontFiltrada <= 90.0 && distFrontFiltrada > 55.0 &&
    (huecoIzquierda || huecoDerecha) &&
    !posibleObstaculo &&
    (millis() - ultimoTiempoCurva > FRONT_COOLDOWN_CURVA)) {

  confirmacionCurva++;

  if (confirmacionCurva >= UMBRAL_CURVA) {
    estadoEsquive = GIRANDO_CURVA;
    anguloZ_acumulado = 0.0;
    confirmacionCurva = 0;

    if (huecoIzquierda) {
      direccionGiroCurva = 35; // Left turn
    } else {
      direccionGiroCurva = 145; // Right turn
    }
  }
}
```

* **Inertial transition:** In the `GIRANDO_CURVA` state, steering is held at 35° or 145° until the gyroscope measures a real rotation of $\theta_z \ge 63.0^\circ$ (`ANGULO_OBJETIVO_CURVA`).
* **Stabilization state (`COOLDOWN_CURVA`):** After completing the turn, steering is centered at 90° for 200 ms (`TIEMPO_COOLDOWN_CURVA`), and turn detection is disabled for 2000 ms (`FRONT_COOLDOWN_CURVA`) to ignore reflections from the exit wall.

---

### Code Maintainability and Track Parameter Guide

To streamline the calibration process in the pit area, key dynamic parameters are centralized on lines 22 through 35 of `src/current/nano_master.cpp`:

```cpp
// CRITICAL PARAMETERS TO CALIBRATE ON TRACK
const float DIST_DETECCION_FRONT = 75.0; // Distance (cm) to initiate turn
const float ANGULO_OBJETIVO = 72.0;       // Real MPU6050 degrees to complete corner
const unsigned long TIEMPO_COOLDOWN = 1200;// Immunity window after exiting corner (ms)

// CONTROL CONSTANTS
float Kp = 10.33;  // Proportional Gain for centering
float Kd = 14.0;   // Derivative Gain for centering
```

---

## Deployment and Track Operation Guide

In a fast-paced competition environment like WRO, reaction speed in the pit area is as decisive as the code running on the car. A last-minute tweak or battery swap must not turn into a mess of tangled cables or compilation errors due to missing dependencies.

This field guide allows any team member or evaluator to quickly, safely, and repeatably compile, test, and deploy the software for Meteoro (v2.0).

---

### 1. Pre-Compilation Prerequisites

Before plugging USB cables into the pit computer, ensure the development environment contains the exact tools and libraries used during our performance testing.

**Development Environment (IDE)**
* **Arduino IDE 2.x (Primary Environment):** We recommend Arduino IDE version 2.0 or higher for its integrated serial monitor, real-time code completion, and live variable inspection.
* **PlatformIO (VS Code):** For team members who prefer working from the command line or using advanced version control with Git, the project includes a fully prepared PlatformIO configuration.

**Required Libraries and Dependency Management**
Make sure to install the following libraries via the Arduino IDE Library Manager (`Ctrl + Shift + I` / `Cmd + Shift + I`) before compiling the code:
* **`Servo.h` (Native Library):** Drives PWM signal output (at 50 Hz) to control the Ackermann steering servo motor on the Slave board.
* **`Wire.h` (Native Library):** Enables real-time communication at 100 kHz over the I2C bus between the Master microcontroller (Address `0x00`) and the Slave (Address `0x08`).
* **`Pixy2.h` (By Charmed Labs):** Handles configuration and SPI data transfers for the PixyCam2 vision sensor, responsible for visual signal recognition on the track.
* **`NewPing.h` (By Tim Eckel):** Optimizes distance measurements from the three RCWL-1601 ultrasonic sensors, eliminating blocking delays caused by standard `pulseIn()` calls.

---

### 2. Firmware Flashing Steps (Pit Workflow)

Because the vehicle uses a dual microcontroller architecture, firmware must be uploaded independently to each Arduino Nano board.

**Step 1: Flashing the Arduino Nano Master**
1. Connect the Arduino Nano Master board to the computer using the primary Mini-USB cable.
2. Open the development environment and load the project file: `src/current/first_challenge/master_nano.ino`
3. In the IDE **Tools** menu, configure the following settings:
   * **Board:** Arduino Nano
   * **Processor:** ATmega328P (If uploading fails, switch to *ATmega328P (Old Bootloader)*)
   * **Port:** Select the assigned serial port (e.g., `COM3` on Windows or `/dev/ttyUSB0` on Linux/macOS).
4. Click **Upload** (`Ctrl + U`).
5. Open the Serial Monitor at 115200 baud to confirm that the MPU6050 orientation sensor completes its initial Z-axis calibration.

**Step 2: Flashing the Arduino Nano Slave**
1. Disconnect the Mini-USB cable from the Master board and connect it to the Arduino Nano Slave (actuator node).
2. Open the project file: `src/current/first_challenge/slave_nano.ino`
3. Verify that the selected board remains Arduino Nano with the correct processor setting.
4. Click **Upload** (`Ctrl + U`).
5. Once flashing completes, reconnect the internal power cables.

> **Safety Note:** Temporarily disconnect the main 3S power battery pack while flashing firmware over USB to prevent accidental motor startup on the workbench.

---

### 3. Pre-Track Protocol (Pit Stop Checklist)

To ensure operational stability during official competition runs, the team strictly follows the protocol detailed in the repository file: [`pit_stop_checklist.md`](docs/pit_stop_checklist.md).

Key checklist items to review at the pit table before moving Meteoro (v2.0) to the starting area:
* **3S Battery Voltage:** Multimeter reading  $\ge 11.8\text{ V DC}$.
* **Servo Mechanical Adjustment:** Verify centered steering at 90°.
* **Transducer Cleaning:** Wipe dust off the ultrasonic sensors.
* **I2C Bus Test:** Ensure SDA/SCL wiring connections are secure.
* **IMU Calibration:** Place the car on a flat surface before powering on (wait 5 seconds).

---

### 4. Race Run Routine

1. **Positioning:** Place Meteoro (v2.0) inside the 30 cm × 20 cm starting box, aligned parallel to the outer wall.
2. **Logic and Power Activation:** Switch on the main 3S power switch.
3. **Calibration Wait:** Observe the status LED on the Master board until the gyroscope completes its inertial reference calibration.
4. **Launch:** Press the start button. The car executes the `arrancarSuave()` function on the Slave board and begins its autonomous run.

---

### 5. Quick Troubleshooting Guide

| Track Symptom | Probable Cause | Immediate Pit Solution |
| :--- | :--- | :--- |
| **Car does not turn at the first corner** | MPU6050 gyroscope reading failure or frozen I2C bus. | Check SDA/SCL cables and restart the car while keeping it stationary. |
| **Unstable turn / Weaving on straightaways** | Proportional Gain $K_p$ too high or sensor noise. | Adjust $K_p = 10.33$ to $8.5$ in the parameter section of `master_nano.ino`. |
| **Servo motor chatters or loses torque** | Voltage drop on Channel 2 Buck Regulator. | Charge or replace the 3S battery pack. |
| **"Board not found" error during flash** | Incorrect COM port or missing USB chip driver (CH340). | Switch processor setting in the IDE to *ATmega328P (Old Bootloader)*. |

---

## Engineering Logbook and Solved Challenges

During the testing phases of our vehicle Meteoro, the team identified and resolved several technical issues that compromised the stability and precision of the autonomous system. Below, we present the detailed history of the challenges faced and the engineering solutions applied.

---

### Technical Challenges and Implemented Solutions

#### 1. Resets Caused by Sudden Voltage Drops (Brownout)
* **Diagnosis:** When starting the main electric motor, consumption peaks were generated that caused the circuit voltage to drop below 4.5 V. This sudden drop caused unexpected resets of the ATmega328P microcontroller.
* **Solution:** We incorporated a dedicated DSN-MINI-360 Buck voltage regulator to supply a constant, clean 5.0 V exclusively to the entire logic section of the circuit.

#### 2. Interference Between Ultrasonic Sensors (Cross-Talk)
* **Diagnosis:** When emitting `TRIG` pin signals simultaneously across multiple RCWL-1601 sensors, the sound waves bounced back at the same time and interfered with each other, causing a sensor to falsely record the echo sent by a neighboring sensor.
* **Solution:** We established a turn-by-turn measurement schedule, leaving a 15 ms delay between triggers for each sensor. Additionally, we filtered data by taking the median of groups of 4 readings to discard outliers.

#### 3. Steering Adjustment Lockup Due to Error Accumulation (Integral Windup)
* **Diagnosis:** During prolonged turns, the accumulated sum of small deviations locked the `suma_errores` variable at its maximum value. This caused the front wheels to get stuck at an angle when attempting to return to a straight line.
* **Solution:** We set a maximum cap (`LIMITE_INTEGRAL = 1000.0`) to prevent the value from growing excessively and added an instruction to reset the `suma_errores` variable to zero right after completing each turn.

#### 4. Loss of Synchronization in Serial Messages (UART)
* **Diagnosis:** In initial testing, data transmitted between the Master and Slave Arduinos lost the byte arrival sequence, resulting in uncoordinated and unstable movements in the motors and steering.
* **Solution:** We structured a clear message format by assigning a start symbol (`<`), the primary command, and an end symbol (`>`), verifying data validity using a checksum.

---

## Bill of Materials

The selection of components for the Meteoro (v2.0) autonomous vehicle was based on guaranteeing electrical stability, low weight, and rapid response during the run. The following table presents the electronic and mechanical elements used in the prototype, indicating the quantity used, their function within the distributed system, and the link to their datasheet stored in the local folder `docs/datasheets/`.

---

### General Table of Components and Datasheets

| Component | Quantity | Technical Function in Meteoro (v2.0) | Datasheet |
| :--- | :---: | :--- | :---: |
| **Arduino Nano (ATmega328P)** | 2 | **Distributed Processing:**<br>• *Master:* Responsible for reading sensors (RCWL-1601, MPU-6050, PixyCam2) and calculating path corrections (PD control).<br>• *Slave:* Generates electrical PWM signals to control the main motor and steering servo motor. | [Datasheet](docs/datasheets/arduino_nano.PDF) |
| **DSN-MINI-360 Buck Regulator** | 2 | **Isolated Power Regulation:**<br>• *Channel 1:* Steps down main voltage from 11.1 V - 12.6 V to a stable ~5.0 V for logic and sensors.<br>• *Channel 2:* Supplies an independent 5.0 V to the servo motor to prevent sudden power drops to the microcontrollers. | [Datasheet](docs/datasheets/buck_converter_mini_360_dc.pdf) |
| **L298N H-Bridge** | 1 | **Power Module for Drive:**<br>Amplifies current and allows changing the rotation direction of the main 11.1 V DC motor. | [Datasheet](docs/datasheets/control_driver_bridge_h_l298n.PDF) |
| **MPU-6050 Gyroscope / Accelerometer** | 1 | **Inertial Navigation:**<br>Measures vertical-axis yaw rate ($\omega_z$) via the I2C bus to software-calculate precise actual 72° turns. | [Datasheet](docs/datasheets/gyroscope_mpu-6050.md) |
| **RCWL-1601 Ultrasonic Sensor** | 3 | **Environment Reading:**<br>Measures wall distance (Left, Front, and Right) by firing sound bursts at 5.0 V. | [Datasheet](docs/datasheets/ultrasonic_sensor_rcwl-1601.md) |
| **AD002 Servo Motor** | 1 | **Steering Control:**<br>Metal-geared servo configured to adjust front wheels according to the Ackermann steering system. | [Datasheet](docs/datasheets/servo_motor_ad002.md) |
| **Yellow TT DC Motor** | 1 | **Rear Wheel Drive:**<br>DC motor connected to transmission with 90° bevel gears (1:1.5 speed ratio). | [Datasheet](docs/datasheets/tt_motor.md) |
| **3S Li-ion Lithium Batteries** | 3 | **Primary Power Source:**<br>Set of 3 lithium cells in series (11.1 V nominal / 12.6 V fully charged) to power both motors and regulators. | [Datasheet](docs/datasheets/battery_3s.pdf) |

---

### Notes on Organization and Technical Files

The files linked in the **Datasheet** column are part of the static project documentation and are stored in the folder: [`docs/datasheets/`](docs/datasheets/).

---

## Modules and Direct Links

* **Prototype Firmware:** [`src/`](src/)
* **Pinout Table:** [`schematics/`](schematics/)
* **Pit Checklist:** [`docs/`](docs/)

---

## Photographic and Multimedia Registry

### Vehicle Views

The 5 mandatory photographs are available in the `photos/vehicle/` folder:

* **Front View:** `photos/vehicle/front_view.jpg`
* **Rear View:** `photos/vehicle/rear_view.jpg`
* **Left Side View:** `photos/vehicle/left_view.jpg`
* **Right Side View:** `photos/vehicle/right_view.jpg`
* **Top View:** `photos/vehicle/top_view.jpg`
* **Bottom View** `photos/vehicle/bottom_view.jpg`

---

### Video Demonstration (YouTube)

* **Open Challenge Video:** [Open Challenge Course](https://youtu.be/mJ1lY1bOVQc)

---

## License

This project is distributed under the **MIT** license. See the `LICENSE` file for more details.

---

<div align="center">

© 2026 **The Pits JO** — Jesús Obrero Technical Institute.  
All rights reserved. Distributed under the [MIT License](LICENSE).

</div>

---

<div align="center">

# WRO 2026 — Futuros Ingenieros
### **Equipo:** The Pits JO &nbsp;|&nbsp; **Robot:** Meteoro
**Instituto Técnico Jesús Obrero (ITJO)**






---

> 🇬🇧 **Note for international judges:** You can read the official main documentation in English at [`README.md`](https://github.com/jorshuamora-itjo/WROITJO2026/blob/main/README.md#wro-2026--future-engineers).

---

</div>

## Materiales de Ingeniería

Este repositorio contiene todos los materiales de ingeniería, modelos CAD, diagramas esquemáticos, código fuente y documentación técnica del vehículo autónomo **Meteoro**, desarrollado por el equipo **The Pits JO** del **Instituto Técnico Jesús Obrero (ITJO)** para la competencia **WRO Future Engineers 2026**.

### Contenido del Repositorio

* **[`README.md/`](https://github.com/jorshuamora-itjo/WROITJO2026/blob/main/README.md#wro-2026--future-engineers)**: Documentación técnica principal en inglés.
* **[`README_ES.md/`](https://github.com/jorshuamora-itjo/WROITJO2026/blob/main/README.md#wro-2026--futuros-ingenieros)**: Documentación técnica completa en español.
* **[`LICENSE`](LICENSE/)**: Licencia de código abierto MIT correspondiente al equipo The Pits JO.
* **[`.gitignored`](.gitignored/)**: Archivo de configuración para ignorar temporales y binarios de compilación.
* **[`src/`](src/)**: Diferentes códigos del software de control para todos los componentes que fueron programados para participar en la competencia.
* **[`models/`](models/)**: Archivos de los modelos utilizados por impresoras 3D, máquinas de corte láser y máquinas CNC para fabricar los elementos del vehículo.
* **[`photos/`](photos/)**: Galería fotográfica unificada que contiene tanto fotos oficiales del equipo, vistas del carro y registros del proceso de armado y programación.
* **[`video/`](video/)**: Archivo con el enlace directo al video de demostración de manejo en pista.
* **[`schematics/`](schematics/)**: Diagramas esquemáticos de los componentes electromecánicos, ilustrando todos los elementos (componentes electrónicos y motores) utilizados en el vehículo y cómo se conectan entre sí.
* **[`docs/`](docs/)**: Documentación adicional, hojas de datos, diagramas de flujo y listas de verificación en foso.

---

> **Aclaración Técnica de Nomenclatura**
> 
> Para facilitar la lectura de la documentación y evitar confusiones a lo largo de este proyecto, utilizamos la siguiente norma:
> 1. **Pit Dinoco (Versión 1.1):** Es nuestro primer auto experimental. Con él aprendimos las bases de la competencia y detectamos las principales fallas a corregir.
> 2. **Meteoro (Versión 2.0):** Es el vehículo definitivo de competencia. Nace del rediseño completo de la parte mecánica, los circuitos de potencia y el programa de control.

---

## Comparativa Visual de los Prototipos

| Criterio de Diseño | Pit Dinoco ($v1.1$) | Meteoro ($v2.0$) |
| :--- | :--- | :--- |
| **Estructura** | Piso único (monocapa) con cables expuestos. | Chasis modular de doble piso con canaletas internas. |
| **Dirección** | Giro simple con servo expuesto a desgaste. | Geometría Ackermann con mecanismo de Yugo Escocés. |
| **Tracción** | Engranajes planos visibles. | Motor longitudinal con engranajes biselados a 90°. |
| **Reparto de Peso** | Baterías atrás (provocaba subviraje). | Baterías al centro del chasis inferior (equilibrio 50/50). |
| **Sensores de Distancia** | Módulos HC-SR04 pegados al frente. | Sensores RCWL-1601 integrados dentro del alerón F1. |

---

## Introducción

El equipo **The Pits JO** está integrado por estudiantes del 6.º año de Educación Media Técnica del **Instituto Técnico Jesús Obrero (ITJO)**. Nuestra formación académica abarca las especialidades de Electrónica y Telemática, lo que nos brindó las herramientas necesarias para construir un auto autónomo desde cero.

Aunque en la práctica diaria en el taller aplicamos la filosofía de *"todos hacemos todo"* (armar, soldar, programar y probar en pista), distribuimos la responsabilidad principal según la especialidad de cada integrante:

| Integrante | Mención Académica | Roles Principales | Contribuciones Clave y Trabajos Cruzados |
| :--- | :--- | :--- | :--- |
| **Samuel Castillo** | Técnico Profesional Industrial en Electrónica | Diseñador Mecánico 3D, Mantenimiento e Integración Electromecánica | Diseñó en 3D las piezas y el chasis de los prototipos  $v1.1$  y  $v2.0$, calibró el sistema de dirección, fabricó los engranajes a medida y apoyó en las rutinas de prueba de los motores. |
| **Jorshua Mora** | Técnico Profesional Industrial en Telemática | Programador Principal de Software, Especialista en Visión y Pits | Desarrolló el código base, configuró el sensor de visión PixyCam2, atendió el mantenimiento rápido en la zona de competencia (pits) y ayudó a conectar la red de cables. |
| **Winston Garrido** | Técnico Profesional Industrial en Electrónica | Algoritmos de Control PID, Diseñador de Esquemas y Gestión de Repositorio | Calibró el sistema de control de trayectoria  $PD$, diseñó la red de alimentación eléctrica, dibujó los esquemáticos y organizó toda la documentación técnica en GitHub. |

> **Nota sobre Orientación Técnica**  
> Por recomendación y petición expresa de nuestro mentor técnico, la estructura arquitectónica del código y la geometría de la dirección fueron sometidas a intensas pruebas de repetición en pista antes de ser aprobadas e instaladas en el prototipo Meteoro ($v2.0$).

---

## Diagnóstico del Prototipo v1.1 ("Pit Dinoco") y Lecciones Aprendidas

Al finalizar nuestra primera participación con Pit Dinoco, analizamos detalladamente su comportamiento para entender por qué cometía errores en la pista. Este análisis nos reveló cuatro problemas mecánicos y eléctricos clave:

* **Cables Expuestos y Doblados:** Al no tener un camino ordenado para los cables, estos rozaban con las partes móviles o se doblaban en exceso, provocando fallas o falsos contactos involuntarios.
* **Reparto de Peso Desequilibrado:** Las baterías de litio estaban colocadas en la parte trasera del auto. Esto hacía que la parte delantera quedara muy liviana, perdiendo agarre y haciendo que el auto *"se fuera de frente"* (subviraje) en las curvas cerradas de 90°.
* **Interferencia de Sensores con las Ruedas:** Los sensores de ultrasonido estaban instalados muy cerca de las ruedas delanteras. Cuando el servomotor giraba al máximo, las ruedas golpeaban los sensores físicamente.
* **Desgaste en la Dirección:** El brazo mecánico conectado al servomotor era plano y de plástico simple. Con el uso continuo y el calor de la fricción, el plástico se ablandaba y se barría, perdiendo la alineación del centro.

### Nuevos Principios de Diseño Arquitectónico para "Meteoro" (v2.0)

Tomando como base los errores de Pit Dinoco, establecimos cuatro pilares esenciales para construir a Meteoro:

1. **Facilidad de Mantenimiento:** Diseñar un sistema donde se puedan cambiar las baterías o revisar las placas sin necesidad de desarmar todo el vehículo en la mesa de trabajo.
2. **Orden y Protección Eléctrica:** Crear canaletas internas que guíen los cables y mantengan separados los cables de alimentación (potencia) de los cables de datos (señales).
3. **Resistencia Mecánica:** Imprimir las piezas de alto impacto con patrones de relleno resistentes (Giroide al 20% y 5 capas de pared) para soportar vibraciones y posibles choques.
4. **Dirección Precisa:** Adoptar un sistema de dirección estilo F1 guiado por la geometría Ackermann y el mecanismo de Yugo Escocés.

---

## Inspiraciones Técnicas y Cambios de Ingeniería

Mantuvimos la combinación que nos dio excelentes resultados en durabilidad: chasis principal en impresión 3D (PLA+/PETG) y electrónica estándar.

Reemplazamos los sensores tradicionales HC-SR04 por el modelo **RCWL-1601**. Aunque se conectan exactamente igual (pines `VCC`, `TRIG`, `ECHO` y `GND`), este nuevo modelo ofrece ventajas marcadas en espacio y precisión:

| Parámetro Técnico | Módulo Anterior: HC-SR04 | Módulo Actual: RCWL-1601 | Impacto en el Vehículo Meteoro |
| :--- | :--- | :--- | :--- |
| **Dimensiones** | Estándar (45 mm  $\times$  20 mm) | Compacto (21 mm  $\times$  18 mm) | Permite empotrar los tres sensores dentro del alerón frontal. |
| **Voltaje de Trabajo** | 5.0V DC rígido | 3.0V a 5.5V DC | Soporta pequeñas variaciones de voltaje sin fallar. |
| **Ángulo de Visión** | $\approx 15^\circ$ (propenso a ecos) | $< 12^\circ$ (haz estrecho) | Evita lecturas falsas al rebotar en paredes en diagonal. |
| **Precisión de Medida** | $\pm 3\text{ mm}$ | $\pm 1\text{ mm}$ | Proporciona medidas estables para corregir la trayectoria suavemente. |

### Integración del Alerón Frontal F1

Para mejorar la rapidez de respuesta en las esquinas, estudiamos soluciones aplicadas por equipos internacionales de la WRO, tomando como inspiración la disposición de sensores del equipo **GammaVersion** (campeones de España WRO).

* **Ventaja Cinemática:** Al colocar los sensores por delante del eje delantero de las ruedas, el vehículo "ve" las paredes con anticipación espacial antes de ingresar físicamente a la curva.
* **Protección contra Impactos:** Diseñamos carcasas de plástico rígido con una tolerancia de ajuste de 0.1 mm que protegen las cápsulas de los sensores ante cualquier roce contra los muros.
* **Orientación Espacial:** Para mantener el vehículo dentro de las dimensiones máximas permitidas (30 cm  $\times$  20 cm), colocamos los sensores laterales en posición vertical y el sensor frontal en posición horizontal.

---

## Especificaciones Mecánicas y Planos

Antes de modelar en la computadora, dibujamos los planos a escala real sobre papel milimetrado para verificar que el auto estuviera dentro de las reglas de la competencia:

* **Largo Total:** 26 cm (Límite máximo permitido: 30 cm)
* **Ancho Total:** 13 cm (Límite máximo permitido: 20 cm)
* **Diámetro de Ruedas:** 40 mm (Ancho: 20 mm)

### Reingeniería del Tren de Transmisión: Engranajes Biselados Custom 3D

Al reubicar las baterías en el piso inferior centrado, tuvimos que colocar el motor DC en sentido longitudinal (paralelo al chasis). Como las piezas comerciales no nos daban la relación de giro exacta que necesitábamos, diseñamos e imprimimos en 3D un conjunto de **engranajes biselados a 90°**:

$$\text{Relación de Transmisión} = \frac{\text{Dientes del Engranaje Conducido}}{\text{Dientes del Engranaje Motriz}} = \frac{24}{16} = 1.5$$

Esta relación  $1:1.5$  ofrece el equilibrio justo entre aceleración de arranque y velocidad máxima para desplazar los  $\approx 660\text{ g}$  de peso de nuestro auto.

---

## Mecanismo de Dirección Ackermann y Convergencia de Ejes

Para evitar que las ruedas delanteras arrastren o patinen al dar curvas de 90°, implementamos una geometría de dirección Ackermann accionada por un servomotor **AD002** mediante una guía con pasador (basada en el Yugo Escocés).

**Condición Cinemática Ideal:**

$$\cot(\theta_{\text{ext}}) - \cot(\theta_{\text{int}}) = \frac{w}{L}$$

Donde $w = 128\text{ mm}$ (distancia entre ruedas delanteras) y $L = 165\text{ mm}$ (distancia entre ejes delantero y trasero).

**Ajuste de Giro en Pista:**

Ajustamos el punto donde convergen las líneas de la dirección 2.5 cm por detrás del eje trasero. Esto brinda un comportamiento ideal:

* **En Tramos Rectos:** El auto se mantiene firme sin hacer movimientos bruscos o zigzags.
* **En Curvas:** La rueda interna ($\theta_{\text{int}}$) gira con un ángulo mayor que la rueda externa ($\theta_{\text{ext}}$), haciendo que la vuelta sea limpia y sin fricción excesiva.

---

## Estructura de Doble Piso y Ruteo Eléctrico

Meteoro está dividido en dos niveles independientes:

* **Planta Inferior (Base Mecánica y Potencia):** Contiene el paquete de baterías Li-ion 3S centrado, el motor de tracción con sus engranajes a 90°, la dirección servoguiada y el alerón frontal F1. Cuenta además con una escotilla inferior para cambiar la batería en segundos.
* **Planta Superior (Cerebro Lógico y Visión):** Sostiene el controlador de motor L298N, la cámara PixyCam2 y los dos microcontroladores Arduino Nano (Maestro y Esclavo). Su carcasa protege el servomotor y mantiene todos los cables ordenados por canaletas.

---

## Estrategia de Navegación de Meteoro para Reto Abierto

La estrategia de navegación de Meteoro utiliza una arquitectura de control de monitoreo constante (bucle cerrado) dividida en tres pilares: lectura y filtrado EMA, Máquina de Estados Finitos (FSM) y controladores en tiempo real.

### Definición del Algoritmo por Estados

#### Estado RECTA (Centrado PD Adaptativo)
En tramos rectos, el vehículo busca mantener una distancia equivalente respecto a las paredes laterales izquierda y derecha:

$$e(t) = \frac{\text{US}_{\text{der}} - \text{US}_{\text{izq}}}{2}$$

Para evitar tambaleos o sobre-correcciones bruscas causadas por pequeñas imperfecciones en el acrílico, se aplica una **Zona de Tolerancia o Zona Muerta (Deadband)** de $\pm 5.0\text{ cm}$:

* Si $|e(t)| \le 5.0\text{ cm} \implies \text{error} = 0$
* Si $e(t) > 5.0\text{ cm} \implies \text{error} = e(t) - 5.0$
* Si $e(t) < -5.0\text{ cm} \implies \text{error} = e(t) + 5.0$

El ángulo de dirección final se calcula mediante la acción del controlador Proporcional-Derivativo (PD):

$$\text{Salida PD} = K_p \cdot \text{error} + K_d \cdot \frac{d e(t)}{dt}$$

$$\theta_{\text{dirección}} = \theta_{\text{neutral}} + \text{Salida PD}$$

Donde $\theta_{\text{neutral}} = 92^\circ$, $K_p = 10.33$  y  $K_d = 14.0$.

---

#### Estado CURVA (Giro Asistido por Giroscopio MPU6050)
Cuando el sensor frontal detecta una pared a una distancia $\le 75.0\text{ cm}$, la FSM cambia al estado **CURVA**:

* **Determinación del Sentido (Primera Esquina):** Si es la primera esquina del recorrido ($\text{sentidoPista} == 0$), se comparan las lecturas de los sensores laterales:
    * **Si `US_izq` > `US_der`:** Sentido Antihorario (Ángulo 65°)
    * **Si `US_izq` ≤ `US_der`:** Sentido Horario (Ángulo 115°)
  
  Este valor se guarda en  $\text{sentidoPista}$  y fija la dirección de giro para todas las curvas siguientes del circuito.

* **Cálculo del Ángulo de Giro Acumulado / Yaw ($\theta_z$):** A partir de la velocidad de giro medida en el eje Z ($\omega_z$), se calcula la variación del ángulo acumulado:

$$\theta_z(t) = \theta_z(t - \Delta t) + \left( \frac{\text{Gyro Z}_{\text{crudo}} - \text{offset}_z}{131.0} \right) \cdot \Delta t$$

* **Criterio de Salida:** El giro se mantiene de forma activa hasta que el valor absoluto de la rotación acumulada alcanza la meta fijada:

$$|\theta_z(t)| \ge \theta_{\text{objetivo}} \quad (\theta_{\text{objetivo}} = 72.0^\circ)$$

---

#### Estado COOLDOWN (Pausa de Protección Post-Curva)
Al finalizar el giro de  $72^\circ$, el vehículo entra en un periodo de estabilización (**COOLDOWN**) por  $1200\text{ ms}$. Durante este intervalo:

1. Se reinicia la memoria del término derivativo ($\text{error anterior} = 0$).
2. Se pausa o ignora temporalmente la lectura del sensor frontal para evitar lecturas erróneas producidas por la inercia del giro o la pared lateral saliente.
3. Se reanuda el control PD con las lecturas laterales para estabilizar la trayectoria antes de regresar al estado **RECTA**.

---

### Filtrado de Datos de Sensores (Filtro EMA Híbrido)

Los sensores de ultrasonido a veces presentan fallas de lectura (*outliers*) o marcajes erróneos de $0\text{ cm}$ debido al rebote del sonido. Para solucionar esto, el algoritmo aplica un filtro híbrido **EMA (Exponential Moving Average)** con umbral de apertura:

```cpp
// Si el sensor detecta espacio abierto (> 70 cm) o error (0 cm),
// responde instantáneamente para no perder la apertura de curva.
// En rangos normales (muros cercanos), aplica suavizado con alpha = 0.4.

float filtrarEMA(float lecturaActual, float lecturaAnterior, float alpha = 0.4) {
    if (lecturaActual == 0 || lecturaActual > 70.0) {
        return lecturaActual; // Respuesta instantánea en aperturas/errores
    }
    return (alpha * lecturaActual) + ((1.0 - alpha) * lecturaAnterior);
}
```

---

## Estrategia de Navegación de Meteoro para Reto de Obstáculos

Para superar con éxito el Reto de Obstáculos, el vehículo autónomo Meteoro hace evolucionar su sistema de control. Sobre la base del centrado de carril mediante el algoritmo PD y la máquina de estados finitos (FSM), integramos un sistema de visión artificial en tiempo real a través de la cámara PixyCam 2, el cual trabaja en perfecta sincronía con la unidad de medición inercial MPU6050.

Mantenemos nuestra arquitectura de procesamiento distribuido Maestro-Esclavo conectada mediante el bus I2C a una frecuencia de 100 kHz. De esta manera, el microcontrolador Maestro asume la responsabilidad de procesar las imágenes y ejecutar la lógica de decisiones, mientras que el Esclavo se dedica exclusivamente a accionar la dirección Ackermann y el motor de tracción en el puente H.

---

### 1. Percepción Visual y Filtro Anti-Falsos Positivos

La PixyCam 2 se encarga de identificar y clasificar las señales del circuito mediante el reconocimiento de dos marcas cromáticas bien definidas:
* **Firma 1 (Verde):** Indica un obstáculo que el vehículo debe esquivar pasando por la **IZQUIERDA**.
* **Firma 2 (Roja):** Indica un obstáculo que debe esquivarse pasando por la **DERECHA**.

#### Filtro de Proximidad y Antirrebote (Debounce)
En un entorno de competencia, los reflejos de luz en el suelo o los destellos lejanos pueden generar lecturas erróneas. Para evitar maniobras bruscas o falsos esquives, implementamos una validación en dos pasos:
1. **Filtro por Dimensión Vertical ($h$):** El sistema ignora cualquier marca lejana o ruido visual. Solo se consideran válidos los bloques cuya altura en píxeles se encuentre dentro del rango operacional de proximidad ($60\text{ px} \le h \le 240\text{ px}$).
2. **Antirrebote Temporal por Tramas (Debounce):** Exigimos que la firma de color sea detectada de manera ininterrumpida durante al menos 3 tramas consecutivas (`UMBRAL_CONFIRMACION = 3`). Únicamente al cumplir esta condición se activan las banderas de maniobra (`verdeConfirmado` o `rojaConfirmada`).

---

### 2. Máquina de Estados Finitos (FSM) y Jerarquía de Prioridades

La máquina de estados del microcontrolador Maestro (`EstadoEsquive`) organiza el comportamiento del auto bajo una estructura jerárquica estricta. Esto evita conflictos cuando coinciden lecturas de visión, ultrasonido u orientación inercial:

#### Matriz de Prioridades de Decisiones

| Prioridad | Condición de Activación | Estado Activado | Acción Principal |
| :---: | :--- | :--- | :--- |
| **1 (Máxima)** | `verdeConfirmado` o `rojaConfirmada` | `ESQUIVANDO_IZQ` / `DER` | Inicia de inmediato la secuencia inercial de esquive. |
| **2 (Media)** | $d_{\text{front}} \le 90\text{ cm}$ y espacio abierto lateral | `GIRANDO_CURVA` | Ejecuta un giro inercial de 63° hacia la apertura. |
| **3 (Base)** | Sin obstáculos ni giros pendientes | `RECTA_NORMAL` | Centra el auto en el carril usando el control PD ($\text{Zona Azul} = \pm 3.5\text{ cm}$). |

---

### 3. Algoritmo de Esquive en 3 Fases (Control Inercial Cerrado)

En lugar de basar las maniobras invasivas en temporizadores fijos —los cuales fallan cuando cambia el agarre de los neumáticos o disminuye la carga de la batería—, Meteoro utiliza la medición de orientación del giroscopio MPU6050. Esto nos asegura un cambio de carril preciso y una reincorporación en trayectoria paralela a la pista.

#### Secuencia Evasiva para Obstáculo Verde (Paso por la Izquierda)

1. **Fase 1: Desvío Diagonal (`ESQUIVANDO_IZQ`):**
   * **Dirección:** Se ajusta el servo a 125° (volante girado a la derecha).
   * **Criterio de transición:** El giroscopio integra la velocidad angular hasta registrar una rotación neta de $\theta_z \ge +10.0^\circ$ (o hasta que la marca visual supere la coordenada $x \ge 220\text{ px}$).

2. **Fase 2: Rebase Paralelo (`REBASANDO_IZQ`):**
   * **Dirección:** Se centra la dirección exactamente a 90°.
   * **Criterio de transición:** El auto avanza recto en el carril opuesto para rebasar el obstáculo durante $t_{\text{rebase}} = 600\text{ ms}$.

3. **Fase 3: Enderezado y Reincorporación (`ENDEREZANDO_IZQ`):**
   * **Dirección:** Se aplica contravolante con la dirección a 45°.
   * **Criterio de transición:** Se monitorea la lectura del giroscopio hasta que la inclinación acumulada regrese a $\theta_z \le 0.0^\circ$ (cancelando la inclinación inicial), o bien transcurra un tiempo máximo de protección de 200 ms. Al completarse, el sistema retorna suavemente al estado `RECTA_NORMAL`.

> **Nota:** La maniobra para esquivar el Obstáculo Rojo aplica una geometría simétrica inversa: giro inicial a 35° hasta alcanzar $\theta_z \le -10.0^\circ$, avance centrado a 90° durante 600 ms y contravolante de enderezado a 135°.

---

### 4. Detección Adaptativa de Esquinas ("Hueco Lateral")

Para evitar que el auto confunda la pared de una esquina cercana con un obstáculo que deba esquivar, el algoritmo combina de forma inteligente la información de la PixyCam y de los tres sensores de ultrasonido:

1. **Inmunidad por Memoria de Cámara:** Si la cámara detectó cualquier marca cromática durante el último segundo (`millis() - ultimoTiempoBloque < 1000 ms`), la activación de giros de pista se inhabilita de forma automática.
2. **Criterio de Vía Abierta ("Hueco Lateral"):** El sistema detecta la llegada a una esquina evaluando la apertura repentina de un muro lateral ($d_{\text{izq}} > 90\text{ cm}$ o $d_{\text{der}} > 90\text{ cm}$) combinada con la presencia de la pared frontal en rango de aproximación ($55\text{ cm} < d_{\text{front}} \le 90\text{ cm}$).
3. **Confirmación e Integración de Curva:** Tras confirmar dos lecturas válidas consecutivas (`UMBRAL_CURVA = 2`), se ingresa al estado `GIRANDO_CURVA` fijando la dirección a 35° o 145° según el lado del hueco detectado. El viraje se mantiene de forma activa hasta que el MPU6050 contabiliza un giro real de $\theta_z = 63.0^\circ$.
4. **Protección de Salida (`COOLDOWN_CURVA`):** Una vez completada la curva, se centra el servo durante 200 ms para estabilizar la marcha y se activa un bloqueo temporal de 2000 ms (`FRONT_COOLDOWN_CURVA`) que impide registrar falsos giros con el muro de salida.

---

### 5. Comunicación y Arquitectura Distribuida I2C

Para evitar retrasos en el ciclo de cálculo de control PD causados por el tiempo que toma procesar la cámara y las lecturas de sonido, la ejecución física de los motores está totalmente separada en el microcontrolador Esclavo:
* **Transmisión de Mensajes:** El Maestro genera y transmite paquetes livianos de 2 bytes con el formato: `[ángulo_destino, velocidad_actual]`.
* **Procesamiento por Interrupción:** El Esclavo recibe los comandos mediante la rutina `Wire.onReceive()`, guardando los valores en variables declaradas como `volatile`. Esto garantiza que la actualización física del ángulo del servo y la potencia del motor se realice en el ciclo principal de forma inmediata, limpia y segura.

---

## Diseño y Evolución Mecánica

### Diagnóstico Post-Mortem y Desafíos Mecánicos en Pit Dinoco (v1.1)

El análisis de rendimiento durante nuestra primera participación en pista nos dio el diagnóstico real que no podíamos observar del todo durante las pruebas en el taller. Identificamos cuatro inconvenientes clave de origen mecánico y de distribución física:

* **Organización del Cableado y Falta de Espacio:** En el intento de reducir las dimensiones al mínimo en una sola capa (monocapa), saturamos la zona central. Los cables de señal quedaron expuestos al roce constante con las piezas móviles del motor y la transmisión, lo que provocó fallas intermitentes por desgaste de los cables.
* **Desbalance del Centro de Gravedad (CG):** Al colocar las baterías de litio en la parte trasera, desplazamos el centro de gravedad fuera de su punto de equilibrio ideal. Esta falta de peso sobre las ruedas delanteras redujo su agarre al suelo, generando un deslizamiento frontal evidente (subviraje) al tomar curvas de 90°.
* **Obstáculo Físico en la Dirección:** Los sensores de ultrasonido delanteros chocaban directamente con las ruedas al girar al máximo, lo que limitaba el ángulo de viraje del vehículo.
* **Desgaste del Brazo de Dirección:** El brazo del servomotor original (impreso y adaptado manualmente en plástico) no soportó el uso continuo. La fricción constante generó calor y terminó barriendo los dientes del engrane, desalineando el punto neutro de la dirección.

---

### Comparativa de Arquitectura Mecánica: v1.1 vs v2.0

Mantuvimos la combinación de materiales que nos dio buenos resultados: la integración de piezas impresas en 3D (PLA+/PETG) y componentes electrónicos estándar.

Sin embargo, para corregir las debilidades estructurales, rediseñamos el chasis por completo. A continuación se detallan las mejoras implementadas:

| Criterio Constructivo | Prototipo Inicial: Pit Dinoco (v1.1) | Prototipo Competitivo: Meteoro (v2.0) | Impacto Mecánico y Dinámico |
| :--- | :--- | :--- | :--- |
| **Distribución del Chasis** | Una sola capa plana con componentes expuestos. | Doble piso modular interconectado. | Separa la zona de potencia de la electrónica de control y protege los componentes. |
| **Geometría de Dirección** | Pivote directo central (giro simétrico). | Geometría Ackermann accionada por Yugo Escocés. | Elimina el arrastre no deseado de las ruedas en curvas cerradas. |
| **Transmisión Trasera** | Engranajes rectos expuestos en el mismo plano. | Engranajes cónicos a 90° impresos en 3D. | Permite colocar el motor a lo largo del chasis y liberar espacio interior. |
| **Ubicación de Baterías** | Colocadas en la parte trasera (detrás del eje). | Compartimento inferior centrado (entre los dos ejes). | Equilibra el centro de gravedad (50/50) y elimina el deslizamiento frontal. |
| **Montaje de Sensores** | Soportes independientes al lado de las ruedas. | Alerón frontal tipo F1 con protección anticolisión. | Mejora la anticipación de lectura y protege los sensores ante choques. |
| **Mantenimiento en Pits** | Desarme total necesario para cualquier cambio. | Tapa de acceso rápido en el piso inferior. | Permite cambiar baterías en segundos sin tocar la electrónica. |

---

### Reingeniería Mecánica en Meteoro (v2.0)

#### 1. Alerón Frontal Integrado F1 (Inspiración "GammaVersion")
Tomando como referencia la distribución de sensores del equipo **GammaVersion** en la WRO, diseñamos una estructura frontal tipo alerón mediante impresión 3D:

* **Lectura Anticipada:** Ubicar los tres sensores de ultrasonido por delante del eje delantero permite al sistema detectar los muros con mayor anticipación antes de que el cuerpo del vehículo ingrese a la curva.
* **Protección Anticolisión:** Los sensores se encajan firmemente en carcasas rígidas con un ajuste exacto de 0.1 mm, funcionando además como un parachoques protector.
* **Distribución Eficiente:** Los sensores laterales se colocaron en posición vertical y el central en horizontal para no superar las dimensiones máximas permitidas de 30 cm × 20 cm.

---

#### 2. Geometría de Dirección Ackermann
Reemplazamos el pivote simple por un sistema de dirección geométrica tipo Ackermann movido por un servomotor **AD002** con engranajes metálicos, conectado mediante una guía ranurada con pasador (mecanismo de Yugo Escocés).

$$\cot(\theta_{\text{ext}}) - \cot(\theta_{\text{int}}) = \frac{w}{L}$$

Donde  $w = 128\text{ mm}$  (ancho entre ruedas) y  $L = 165\text{ mm}$  (distancia entre ejes).

Esta configuración hace que la rueda interior ($\theta_{\text{int}}$) gire en un ángulo mayor que la exterior ($\theta_{\text{ext}}$), haciendo que ambas sigan el trazado natural de la curva sin derrapar.

* **Calibración de Estabilidad:** Ajustamos la geometría para que el punto de alineación quede 2.5 cm por detrás del centro del eje trasero. Esto mantiene al vehículo firme y estable en rectas sin quitarle agilidad en los giros de 90°.

---

#### 3. Transmisión Rediseñada: Engranajes Cónicos Personalizados a 90°
Para colocar las baterías en el centro del piso inferior, orientamos el motor a lo largo del chasis. También diseñamos e imprimimos un par de **engranajes cónicos a 90°**:

$$\text{Relación de Transmisión} = \frac{\text{Dientes Conducidos}}{\text{Dientes Motrices}} = \frac{24}{16} = 1.5$$

Esta relación de 1:1.5 ofrece el equilibrio justo entre fuerza de arranque y velocidad máxima para el peso total del vehículo (660 g).

---

#### 4. Distribución Modular de Doble Piso
La estructura de Meteoro simplifica las revisiones y reparaciones organizándose en dos niveles:

* **Planta Inferior (Transmisión y Potencia):** Aloja el paquete de baterías Li-ion 3S en el centro, el motor principal con sus engranajes cónicos, el servomotor de dirección metálico y el alerón delantero. Incluye una tapa de acceso rápido por debajo para cambiar las baterías cómodamente.
* **Planta Superior (Control y Sensores):** Sostiene los microcontroladores, el módulo del motor L298N, la cámara PixyCam2 y canaletas internas que mantienen los cables de señal aislados de los cables de corriente.

---

#### 5. Verificación de Dimensiones
Antes del modelado final en software CAD, trazamos las medidas sobre papel milimetrado para garantizar el cumplimiento del reglamento WRO (30 cm × 20 cm):

* **Largo Total:** 260 mm
* **Ancho Total:** 130 mm
* **Diámetro de Ruedas:** 40 mm (Ancho: 20 mm)

---

## Arquitectura Electrónica y Sistema de Potencia

En la robótica autónoma, la estabilidad del software depende totalmente de la solidez del sistema eléctrico que lo respalda. En nuestro primer prototipo (Pit Dinoco), sufríamos reinicios inesperados en el cerebro del carro debido a interferencias de energía provocadas por el motor principal y a las exigencias puntuales del motor de dirección.

Para Meteoro (v2.0), rediseñamos por completo la arquitectura electrónica dividiendo el trabajo entre dos microcontroladores conectados en red y construyendo un sistema de energía separado e independiente para cada necesidad.

---

### Arquitectura Lógica Distribuida (Maestro / Esclavo vía I2C)

Para evitar retrasos en el envío de señales a los motores mientras se leen sensores al mismo tiempo, repartimos el trabajo entre dos placas Arduino Nano interconectadas mediante el bus de datos I2C (en la dirección `0x08`):

* **Arduino Nano Maestro:** Funciona como el "cerebro" del vehículo. Se encarga de medir las distancias de los tres sensores de ultrasonido, calcular la inclinación con el giroscopio MPU6050, reconocer colores con la cámara PixyCam2 (conectada por bus SPI) y procesar las ecuaciones matemáticas de control para guiar el carro.
* **Arduino Nano Esclavo:** Funciona como el "músculo" del sistema. Recibe de forma rápida la información enviada por el Maestro y acciona directamente el servomotor de la dirección y el módulo L298N que da movimiento al motor principal.

---

### Asignación de Pines (Pinout Map)

Para consultar los esquemas gráficos completos e ilustrados, puedes revisar la carpeta `schematics/` en el repositorio.

#### Mapeo de Pines - Arduino Nano Maestro

| Módulo / Componente | Pin del Componente | Pin Arduino Nano | Tipo de Señal | Nivel Lógico | Función en el Sistema |
| :--- | :--- | :--- | :--- | :--- | :--- |
| **Ultrasonido Izquierdo** | ECHO | D6 | Entrada | 5.0 V | Recepción de eco para pared izquierda |
| | TRIG | D7 | Salida | 5.0 V | Emisión de pulso de ultrasonido |
| **Ultrasonido Derecho** | ECHO | D8 | Entrada | 5.0 V | Recepción de eco para pared derecha |
| | TRIG | D9 | Salida | 5.0 V | Emisión de pulso de ultrasonido |
| **Ultrasonido Frontal** | ECHO | D10 | Entrada | 5.0 V | Recepción de eco para detectar curvas |
| | TRIG | D11 | Salida | 5.0 V | Emisión de pulso de ultrasonido |
| **Giroscopio (MPU6050)** | SDA | A4 | I2C Data | 5.0 V | Lectura de giro en el eje Z |
| | SCL | A5 | I2C Clock | 5.0 V | Reloj de sincronización (100 kHz) |
| **Interconexión I2C (Esclavo)** | SDA | A4 | I2C Data | 5.0 V | Envío de orden de dirección y velocidad |
| | SCL | A5 | I2C Clock | 5.0 V | Canal de reloj compartido |
| **Cámara PixyCam2** | MOSI / MISO / SCK | D11 / D12 / D13 | SPI Bus | 5.0 V | Reconocimiento visual a 60 cuadros por segundo |
| **Alimentación Lógica** | 5V / GND | 5V / GND | Potencia | 5.0 V Reg. | Entrada desde el Regulador Canal 1 |

---

#### Mapeo de Pines - Arduino Nano Esclavo

| Módulo / Componente | Pin del Componente | Pin Arduino Nano | Tipo de Señal | Nivel Lógico | Función en el Sistema |
| :--- | :--- | :--- | :--- | :--- | :--- |
| **Servo de Dirección AD002** | Signal (PWM) | D2 | PWM Salida | 5.0 V | Ajuste de ángulo para dirección Ackermann |
| **Driver L298N (Motor DC)** | IN1 / A1 | D5 | PWM Salida | 5.0 V | Control de velocidad para la tracción |
| | IN2 / A2 | D6 | Salida Digital | 5.0 V | Sentido de marcha (LOW para avanzar) |
| **Interconexión I2C (Maestro)** | SDA | A4 | I2C Data | 5.0 V | Recepción de comandos desde el Maestro |
| | SCL | A5 | I2C Clock | 5.0 V | Canal de reloj compartido |
| **Alimentación Lógica** | 5V / GND | 5V / GND | Potencia | 5.0 V Reg. | Entrada desde el Regulador Canal 2 |

---

### Red de Distribución de Potencia y Regulación

La fuente de energía principal consiste en un paquete de 3 baterías de litio conectadas en serie (3S) que entregan una tensión nominal de 11.1 V (llegando a 12.6 V a carga completa).

Para eliminar por completo las caídas de voltaje que reiniciaban el sistema, dividimos la corriente usando dos reguladores de voltaje independientes (módulos Buck DSN-MINI-360):

| Etapa de Potencia | Fuente de Entrada | Salida Regulada | Componentes Alimentados |
| :--- | :--- | :--- | :--- |
| **Baterías de Litio (3S)** | Paquete 3 × 3.7 V | 11.1 V - 12.6 V Directo | Entrada de energía para el motor principal (Driver L298N) |
| **Regulador Buck 1 (Canal 1)** | Paquete de Litio 3S | 5.0 V DC Regulado | Arduino Nano Maestro, Giroscopio MPU6050, 3 Sensores Ultrasónicos y PixyCam2 |
| **Regulador Buck 2 (Canal 2)** | Paquete de Litio 3S | 5.0 V DC Regulado | Arduino Nano Esclavo y Servomotor AD00S |
| **Masa Común (GND)** | N/A | 0 V | Unión de cables de tierra para todas las placas y sensores |

---

### Beneficios del Aislamiento de Potencia

* **Protección ante Exigencias de Energía:** Cuando el servomotor realiza giros muy marcados en curvas cerradas, consume energía únicamente del Canal 2. Esto evita que el voltaje de la cámara o los procesadores baje del límite operativo de 4.5 V.
* **Filtrado de Interferencia:** El motor de tracción recibe energía directa de la batería. Los reguladores de voltaje aislados limpian los picos de corriente y el ruido eléctrico generados por el driver L298N.
* **Referencia Común de Tierra:** A pesar de tener regulaciones separadas, todos los cables negativos (0 V / GND) se unen en un solo punto para garantizar que la información transmitida por el bus I2C sea clara y precisa.

---

### Esquemáticos Electrónicos de Referencia

En la carpeta [`schematics/`](schematics/) del repositorio se encuentran disponibles las guías visuales de interconexión:

* `schematics/nano_master_diagram.jpg`: Diagrama de conexiones del circuito Maestro (Sensores, Visión, I2C y Canal 1 de Potencia).
* `schematics/nano_slave_diagram.jpg`: Diagrama de conexiones del circuito Esclavo (Motores, Driver L298N, Servomotor y Canal 2 de Potencia).
* `schematics/pinout_table.md`: Documento de consulta rápida para verificación de conexiones durante las pruebas en pits.

---

## Arquitectura de Software y Lógica de Control

### Evolución Histórica del Código (v1 a v4)

El desarrollo del software para nuestro vehículo no ocurrió de la noche a la mañana. Enfrentar la pista real nos enseñó que la teoría pura se estrella rápidamente cuando los sensores rebotan en esquinas abiertas o cuando las ruedas tiemblan por ruido numérico. A continuación, documentamos el proceso evolutivo de nuestras firmas de código guardadas en la carpeta `src/history/` hasta llegar a la versión actual en `src/current/`.

* **Versión 1: Monolítico y Bloqueante (`src/history/v1_pid_control.ino`)**
  * **Arquitectura:** Un solo Arduino Uno ejecutando todo el trabajo de forma secuencial.
  * **Mecanismo:** Medición con la función `pulseIn()`, la cual pausaba el procesador hasta 12 ms por cada sensor. Al medir 3 sensores, el procesador perdía más de 35 ms inmóvil por ciclo.
  * **Falla Crítica:** Al llegar a la esquina, el sensor frontal perdía la pared o leía rebotes erróneos. El algoritmo PID intentaba corregir distancias inexistentes, generando giros bruscos de dirección y choques contra la pared exterior.

* **Versión 2: Transición por Estados (`src/history/v2_pid_switch.ino`)**
  * **Innovación:** Implementamos por primera vez una Máquina de Estados Finita (`RECTA` y `CURVA`) para separar la corrección del carril de la maniobra de giro.
  * **Control:** Reducción automática de velocidad al detectar que se aproximaba un muro (fijada al 80% de la velocidad máxima).
  * **Falla Crítica:** El carro volvía al estado `RECTA` antes de terminar de salir del cruce. Al detectar el muro lateral demasiado cerca inmediatamente después del giro, el PID aplicaba un volantazo inverso instantáneo.

* **Versión 3: Temporizadores y Cooldown (`src/history/v3_fsm_cooldown.ino`)**
  * **Innovación:** Se introdujo la constante `COOLDOWN_CURVA` (1500 ms) para impedir que el auto reingresara al estado de curva inmediatamente tras salir de una.
  * **Dirección:** Primera versión en registrar si la pared abierta estaba a la izquierda o derecha antes de iniciar la maniobra fija.
  * **Falla Crítica:** Depender de tiempos fijos (`DURACION_GIRO = 2500 ms`) causaba descarrilamientos si la batería bajaba su carga: a menor voltaje, el auto recorría menos distancia en el mismo tiempo, quedando apuntando en diagonal.

* **Versión 4: Filtro de Mediana y Detección de Huecos (`src/history/v4_median_filter.ino`)**
  * **Innovación:** Incorporación del filtro de mediana sobre arreglos de 4 muestras (`filtroMediana4`) para ignorar picos de ruido causados por la textura del muro.
  * **Lógica:** Detección de aperturas de carril cuando la distancia medida superaba la `distanciaHueco` (90 cm).
  * **Punto de Quiebre:** Aunque el filtro de mediana limpió la señal, el cálculo de ordenamiento consumía ciclos de procesador apreciables. Además, el auto aún no sabía con certeza absoluta cuánto había rotado sobre su propio eje.

---

### Tabla Comparativa de Evolución de Software

| Criterio Térmico / Lógico | v1 (Monolítico) | v2 (Estados Simples) | v3 (Cooldown) | v4 (Filtro Mediana) | Versión Actual (`src/current/`) |
| :--- | :--- | :--- | :--- | :--- | :--- |
| **Procesador** | 1 Arduino Uno | 1 Arduino Uno | 1 Arduino Uno | 1 Arduino Uno | 2 Arduino Nano (I2C) |
| **Lectura Ultrasónica** | `pulseIn()` bloqueante | `pulseIn()` directo | `pulseIn()` con tiempo | Mediana (4 muestras) | Librería NewPing + EMA |
| **Detección de Giro** | Distancia a pared | Umbral frontal fijo | Distancia + Tiempo | Detección de Hueco | Giroscopio MPU6050 Integrado |
| **Filtro de Ruido** | Sin filtro (Crudo) | Umbral rígido | Umbral rígido | Filtro Mediana 4p | EMA ($\alpha = 0.4$) + Límite 180 cm |
| **Seguridad de Sentido** | Inexistente | Reactivo instantáneo | Bloqueo por evento | Memoria de carácter | `sentidoPista` Permanente (EEPROM/RAM) |

---

### Arquitectura de Red Distribuida (Maestro / Esclavo)

Para garantizar un tiempo de ciclo ($\Delta t$) constante y libre de retrasos en la generación de señales de velocidad, el código actual ubicado en `src/current/` divide la carga computacional en dos procesadores a través del bus I2C a 100 kHz.

#### Análisis del Código Esclavo para Reto Abierto  (`src/current/first_challenge/nano_slave.cpp`)

El microcontrolador Esclavo funciona como un controlador periférico dedicado exclusivamente al movimiento físico de la dirección y la tracción, manteniendo la lógica limpia de interrupciones de tiempo de sensores.

##### 1. Interrupción y Búfer Seguro
Para evitar interferencias de datos mientras se ejecutan las órdenes de los motores, los datos recibidos mediante el evento `Wire.onReceive(recibirDatosI2C)` se almacenan en variables protegidas marcadas con el calificador `volatile`:

```cpp
volatile byte anguloRecibido = 90;
volatile byte velRecibida = 255;
volatile bool actualizarMotores = false;
```

La función que atiende la llegada de datos simplemente toma los valores transmitidos y activa una señal de aviso (bandera), dejando que la activación física de los motores ocurra en el ciclo principal (`loop()`) para no congelar la comunicación I2C:

```cpp
void recibirDatosI2C(int cuantosBytes) {
  if (cuantosBytes >= 2) {
    anguloRecibido = Wire.read();    
    velRecibida = Wire.read(); 
    actualizarMotores = true; // Notifica al ciclo principal
  }
}
```

##### 2. Algoritmo de Arranque Progresivo (`arrancarSuave`)
Al encender el auto desde el reposo, el motor eléctrico exige un pico de corriente inicial (*inrush current*) que puede generar interferencias eléctricas en la línea de alimentación. El programa esclavo previene esto aumentando la velocidad de manera escalonada en cuestión de microsegundos:

```cpp
void arrancarSuave() {
  digitalWrite(pinB, LOW);
  for (int vel = 0; vel <= velRecibida; vel++) {
    analogWrite(pinA, vel);
    delayMicroseconds(3921); // Rampa de aceleración ~1 segundo total
  }
}
```

### Análisis del Código Maestro para Reto Abierto (`src/current/first_challenge/nano_master.cpp`)

El microcontrolador Maestro es el cerebro principal: analiza lo que sucede alrededor con los sensores, mide los giros del auto, administra los cambios de modo y calcula los ajustes necesarios para mantener la ruta ideal.

---

#### Filtrado Digital: Promedio Móvil Exponencial (EMA)

Para eliminar los temblores en las ruedas durante los tramos rectos sin sobrecargar el procesador con ordenamientos de listas complejas, implementamos un filtro de suavizado de datos (EMA).

**Ecuación Matemática:**
$$y[k] = \alpha \cdot x[k] + (1 - \alpha) \cdot y[k-1]$$

Donde:
* $x[k]$ representa la lectura cruda obtenida por el sensor en el instante actual $k$.
* $y[k-1]$ es la distancia filtrada que calculamos en el paso anterior.
* $\alpha = 0.4$ es el factor de suavizado que configuramos mediante pruebas prácticas.

**Tratamiento Espacial de Cero (0 cm = 180 cm):**
Cuando la pared desaparece en un cruce, los sensores ultrasónicos devuelven un valor de 0 cm debido a la ausencia de eco. Interpretamos esto como espacio totalmente libre asignándole una distancia teórica de 180.0 cm, evitando así divisiones por cero o correcciones erróneas:

```cpp
float filtrarLectura(float lecturaCruda, float lecturaAnterior) {
  float lecturaProcesada = lecturaCruda;
  if (lecturaCruda <= 0.0) {
    lecturaProcesada = 180.0; // Espacio abierto en esquina
  }

  // Si detectamos espacio abierto (> 70 cm), permitimos respuesta rápida
  if (lecturaProcesada > 70.0) {
    return lecturaProcesada; 
  }

  // Suavizado EMA para navegación fina cerca de muros
  float alpha = 0.4;
  return (alpha * lecturaProcesada) + ((1.0 - alpha) * lecturaAnterior);
}
```

### Integración Inercial del Giroscopio MPU6050

A diferencia de las versiones anteriores, los giros en la versión actual no dependen de rebotar ondas en muros inexistentes. Calculamos la rotación sumando de forma continua la velocidad de giro ($\omega_z$) medida por el sensor de movimiento MPU6050 a través de la conexión I2C (dirección `0x68`):

**Cálculo del Ángulo de Rotación:**
$$\theta_z = \sum \left( \frac{\text{giroZ}}{131.0} \right) \cdot \Delta t$$

Donde el valor 131.0 LSB/(°/s) corresponde a la escala de sensibilidad de ±250°/s configurada en el sensor MPU6050.

```cpp
// En el bucle dentro del estado CURVA
float giroZ = (leerGiroscopioZ() - offsetZ) / 131.0; 
anguloZ_acumulado += (giroZ * dt);

if (abs(anguloZ_acumulado) >= ANGULO_OBJETIVO) { // ANGULO_OBJETIVO = 72.0°
  estadoActual = COOLDOWN;
  tiempoInicioCooldown = millis();
}
```

### Máquina de Estados Finita y Lógica de Pista

* **Memoria de Sentido de Pista (`sentidoPista`):** Durante el primer giro de la carrera (`sentidoPista == 0`), el vehículo analiza qué lado ofrece mayor apertura y graba permanentemente la dirección del circuito. Una vez asignada la variable, las 11 curvas restantes del recorrido leen directamente `sentidoPista`, ignorando lecturas erróneas causadas por rebotes acústicos.

#### Controlador PD con Zona Muerta (Zona Azul)

En el modo `RECTA`, el vehículo se mantiene centrado entre ambas paredes midiendo la diferencia de centrado  $e(t)$:

$$e(t) = \frac{\text{distDer} - \text{distIzq}}{2}$$

**Filtro de Zona Azul (±5 cm):**
Para evitar correcciones innecesarias por imperfecciones o relieves en la pared de la pista, se aplica una zona muerta de ±5 cm:

```cpp
const float ZONA_AZUL = 5.0; 
float error = 0; 

if (abs(distancia_al_centro) <= ZONA_AZUL) {
  error = 0; 
}
else {
  if (distancia_al_centro > 0) error = distancia_al_centro - ZONA_AZUL; 
  else error = distancia_al_centro + ZONA_AZUL;
}
```

**Ecuación Proporcional-Derivativa:**
$$u(t) = K_p \cdot e(t) + K_d \cdot \frac{e(t) - e(t-\Delta t)}{\Delta t}$$

* **Ganancia Proporcional ($K_p = 10.33$):** Responde a la magnitud del descentrado del vehículo.
* **Ganancia Derivativa ($K_d = 14.0$):** Frena el balanceo lateral prediciendo la velocidad con la que el auto se acerca al muro.
* **Límite Estricto de Giro:** La salida  $u(t)$  está acotada a ±15° alrededor del punto medio del servomotor (92°), restringiendo el ángulo físico de la dirección a la ventana comprendida entre 57° y 127°.

---

### Análisis del Código Esclavo para Reto de Obstáculos (`src/current/second_challenge/slave_nano.cpp`)

En la arquitectura de Meteoro, el microcontrolador Esclavo actúa como un nodo de ejecución periférica. Su responsabilidad principal es abstraer la generación de señales físicas de modulación por ancho de pulso (PWM) para la tracción y la servodirección. De esta manera, se evita que los tiempos de comunicación del bus I2C afecten el rendimiento dinámico y la respuesta física del vehículo.

---

#### 1. Interrupción I2C y Desacoplamiento de Actuación

Para prevenir bloqueos en la recepción de datos y evitar inconsistencias en la escritura de registros mientras el microcontrolador ejecuta instrucciones de control, los paquetes entrantes procesados por la función `Wire.onReceive(recibirDatosI2C)` se almacenan en búferes de memoria protegidos mediante el calificador `volatile`:

```cpp
volatile byte anguloRecibido = 90;
volatile byte velRecibida = 255;
volatile bool actualizarMotores = false;
```

La rutina de atención a la interrupción (ISR) valida la cantidad de bytes recibidos, extrae las órdenes de ángulo y velocidad, y activa de inmediato una bandera de notificación. Este diseño garantiza que la rutina devuelva el control al bus de forma casi instantánea:

```cpp
void recibirDatosI2C(int cuantosBytes) {
  if (cuantosBytes >= 2) {
    anguloRecibido = Wire.read();
    velRecibida = Wire.read();
    actualizarMotores = true; // Notifica al ciclo principal
  }
}
```

#### 2. Ejecución Asíncrona en Bucle Abierto

El bucle principal (`loop()`) evalúa constantemente la bandera `actualizarMotores`. Cuando detecta una actualización, aplica de inmediato los nuevos valores a los actuadores físicos. Esto asegura que la actualización del servomotor (`miServo.write()`) y del puente H (`analogWrite()`) se realice fuera del contexto rígido de la interrupción:

```cpp
void loop() {
  if (actualizarMotores) {
    miServo.write(anguloRecibido);
    analogWrite(pinA, velRecibida);
    digitalWrite(pinB, LOW);
    actualizarMotores = false; // Reinicia la señal de aviso
  }
}
```

---

### Análisis del Código Maestro para Reto de Obstáculos `(src/current/second_challenge/master_nano.cpp)`

El microcontrolador Maestro constituye la unidad central de percepción y toma de decisiones. Coordina el procesamiento de visión en tiempo real enviado por la cámara PixyCam 2, la fusión de distancias ultrasónicas mediante la librería `NewPing` y el cálculo de orientación angular a través del giroscopio MPU6050.

---

#### 1. Percepción Visual y Filtro Anti-Falsos Positivos (Debounce)

Para evitar maniobras de esquive no deseadas causadas por reflejos en la pista o destellos de luz, el algoritmo filtra las firmas de color detectadas mediante un sistema de validación en dos etapas en cascada:

#### A. Filtro por Tamaño de Bloque ($h$)
El sistema descarta cualquier bloque cuya altura en píxeles ($h$) no pertenezca al rango operativo de proximidad. Esto garantiza que solo se reaccione ante obstáculos reales ubicados a una distancia relevante de la defensa frontal:

$$60\text{ px} \le h \le 240\text{ px}$$

#### B. Antirrebote Temporal por Confirmación de Tramas
El algoritmo exige una presencia continua de la misma marca de color a lo largo de $N$ tramas consecutivas (`UMBRAL_CONFIRMACION = 3`). Únicamente cuando se alcanza esta consistencia se activan las banderas lógicas de maniobra (`verdeConfirmado` o `rojaConfirmada`):

```cpp
if (verdeEnFrame) {
  lecturasVerdeConsecutivas++;
  lecturasRojaConsecutivas = 0;
} else if (rojaEnFrame) {
  lecturasRojaConsecutivas++;
  lecturasVerdeConsecutivas = 0;
} else {
  lecturasVerdeConsecutivas = 0;
  lecturasRojaConsecutivas = 0;
}

bool verdeConfirmado = (lecturasVerdeConsecutivas >= UMBRAL_CONFIRMACION);
bool rojaConfirmada = (lecturasRojaConsecutivas >= UMBRAL_CONFIRMACION);
```

#### 2. Filtrado de Distancia y Tratamiento de Eco Perdido

Las lecturas crudas de los tres sensores ultrasónicos se procesan mediante un filtro de Promedio Móvil Exponencial (EMA) para atenuar variaciones bruscas. Cuando el pulso ultrasónico no regresa debido a una apertura en la pared (obteniendo un valor de 0.0 cm en `NewPing`), el algoritmo sustituye el valor nulo por el límite superior práctico del entorno (200.0 cm). Esta saturación controlada evita inconsistencias en las ecuaciones de control:

```cpp
float filtrarLectura(float lecturaCruda, float lecturaAnterior) {
  if (lecturaCruda == 0.0) {
    lecturaCruda = 200.0; // Saturación por ausencia de eco (vía abierta)
  } else if (lecturaCruda <= 2.0) {
    return lecturaAnterior; // Descarte de ruido por contacto o vibración
  }

  float alpha = 0.4;
  return (alpha * lecturaCruda) + ((1.0 - alpha) * lecturaAnterior);
}
```

#### 3. Integración Inercial de Guiñada ($\theta_z$) con MPU6050

El ángulo de orientación sobre el eje vertical ($\theta_z$) se calcula mediante la integración numérica continua de la velocidad angular ($\omega_z$) capturada del registro `0x47` del giroscopio MPU6050 a través de I2C:

$$\theta_z(k) = \theta_z(k-1) + \left( \frac{\text{giroZ} - \text{offsetZ}}{131.0} \right) \cdot \Delta t$$

Donde la constante 131.0 LSB/(°/s) corresponde al factor de escala para la sensibilidad configurada de ±250°/s.

```cpp
float giroZ = (leerGiroscopioZ() - offsetZ) / 131.0;

if (estadoEsquive != RECTA_NORMAL) {
  anguloZ_acumulado += (giroZ * dt);
}
```

#### 4. Máquina de Estados Finitos (FSM) con Jerarquía de Prioridades

La FSM del Maestro organiza el comportamiento global del vehículo estableciendo una estricta jerarquía de decisiones para resolver cualquier conflicto entre la cámara, los sensores ultrasónicos y la IMU:

* **Prioridad 1 (Máxima):** Esquive inercial de obstáculos (`ESQUIVANDO_IZQ` / `ESQUIVANDO_DER`). Se activa de forma inmediata al confirmar una firma cromática.
* **Prioridad 2 (Media):** Giro adaptativo en esquinas por espacio lateral (`GIRANDO_CURVA`). Se activa al detectar la desaparición de un muro lateral junto a la aproximación de la pared frontal.
* **Prioridad 3 (Base):** Centrado automático de carril mediante control PD (`RECTA_NORMAL`). Opera por defecto cuando no hay maniobras ni giros pendientes.

#### 5. Control PD de Carril con Zona Muerta (Zona Azul)

Durante el estado `RECTA_NORMAL`, el vehículo mantiene una trayectoria centrada evaluando el error de desviación lateral $e(t)$:

$$e(t) = \frac{d_{\text{der}} - d_{\text{izq}}}{2}$$

#### A. Filtro de Zona Azul (±3.5 cm)
Para prevenir oscilaciones innecesarias en las ruedas delanteras generadas por pequeñas irregularidades en la pared, el algoritmo aplica una zona muerta de ±3.5 cm:

```cpp
const float ZONA_AZUL = 3.5;

if (abs(distancia_al_centro) <= ZONA_AZUL) {
  error = 0;
} else {
  if (distancia_al_centro > 0) error = distancia_al_centro - ZONA_AZUL;
  else error = distancia_al_centro + ZONA_AZUL;
}
```

#### B. Ecuación de Control y Acotamiento de Salida

Se aplica la acción proporcional y derivativa. Para evitar saltos bruscos en el servo, se limita la razón de cambio de la derivada ($\frac{\Delta e}{\Delta t}$) y se acota la corrección total $u(t)$ a un rango dinámico seguro:

$$u(t) = \text{constrain}\left( K_p \cdot e(t) + K_d \cdot \text{constrain}\left(\frac{e(t) - e(t-\Delta t)}{\Delta t}, -150, 150\right), -17, 17 \right)$$

$$\text{anguloDestino} = \text{constrain}\left( 90 + u(t), 45, 135 \right)$$

#### 6. Algoritmo de Esquive Inercial en 3 Fases

Al confirmar una firma cromática válida, la FSM ejecuta una secuencia de esquive guiada dinámicamente por la orientación del giroscopio:

#### Secuencia de Manejo para Obstáculo Verde (Paso por la Izquierda)

1. **Fase 1: Desvío Diagonal (`ESQUIVANDO_IZQ`):**
   * **Ángulo de dirección:** 125° (viraje inicial).
   * **Criterio de salida:** Se monitorea la inclinación acumulada hasta registrar $\theta_z \ge +10.0^\circ$ (o bien el centroide visual alcance $x \ge 220\text{ px}$).

2. **Fase 2: Rebase Paralelo (`REBASANDO_IZQ`):**
   * **Ángulo de dirección:** 90° (dirección centrada).
   * **Criterio de salida:** El auto avanza recto en el carril opuesto para rebasar el obstáculo durante un intervalo fijo de $t_{\text{rebase}} = 600\text{ ms}$.

3. **Fase 3: Enderezado y Reincorporación (`ENDEREZANDO_IZQ`):**
   * **Ángulo de dirección:** 45° (contravolante opuesto).
   * **Criterio de salida:** La rotación inercial neta cancela la inclinación inicial ($\theta_z \le 0.0^\circ$) o transcurre el tiempo límite de seguridad ($t_{\text{ender}} = 200\text{ ms}$). Cumplida la condición, el sistema regresa limpiamente al estado `RECTA_NORMAL`.

> **Nota:** La maniobra evasiva para el Obstáculo Rojo ejecuta un patrón geométrico simétrico opuesto: ángulo inicial a 35° hasta $\theta_z \le -10.0^\circ$, rebase centrado a 90° por 600 ms y contravolante de enderezado a 135°.
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

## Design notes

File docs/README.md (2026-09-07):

Docs
===

Additional documentation, datasheets, flow charts, and pit checklists.

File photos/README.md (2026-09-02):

Photos
===

Unified photo gallery containing official team photos, vehicle views, and assembly/programming logs.

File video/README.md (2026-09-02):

Video
====

File containing the direct link to the track demonstration video.

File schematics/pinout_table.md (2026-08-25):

# Pinout and Electronic Connections Table

This document describes the detailed electrical architecture, complete pin mapping for the Arduino Nano boards (Master and Slave), communication buses (I2C and SPI), and the two-channel regulated power distribution network powered by lithium batteries.

---

## 1. Pin Mapping - Arduino Nano Master (Navigation, Vision and Sensors)

The Master Arduino Nano processes visual information from the PixyCam2 via SPI, distance measurements from the three RCWL-1601 ultrasonic sensors and angular data from the MPU6050 gyroscope, executing PID control and calculating the steering setpoint.

| Component / Module | Component Pin | Arduino Nano Pin | Signal Type | Voltage Level | Description / Function |
| :--- | :---: | :---: | :---: | :---: | :--- |
| **Left Ultrasonic (RCWL-1601)** | ECHO | D6 | Input | 5.0V Logic | Return pulse duration measurement |
| | TRIG | D7 | Output | 5.0V Logic | Ultrasonic pulse trigger |
| **Right Ultrasonic (RCWL-1601)** | ECHO | D8 | Input | 5.0V Logic | Return pulse duration measurement |
| | TRIG | D9 | Output | 5.0V Logic | Ultrasonic pulse trigger |
| **Front Ultrasonic (RCWL-1601)** | ECHO | D10 | Input | 5.0V Logic | Return pulse duration measurement |
| | TRIG | D11 | Output | 5.0V Logic | Ultrasonic pulse trigger |
| **Gyroscope (MPU6050)** | SDA | A4 (SDA) | I2C Data | 5.0V Logic | Data bus for Z-axis angular velocity estimation |
| | SCL | A5 (SCL) | I2C Clock | 5.0V Logic | I2C clock synchronization (100 kHz) |
| **I2C Interconnection (Slave)** | SDA | A4 (SDA) | I2C Data | 5.0V Logic | Sends angle and speed to Slave Nano (0x08) |
| | SCL | A5 (SCL) | I2C Clock | 5.0V Logic | Shared I2C bus clock |
| **PixyCam2 Camera** | SPI MOSI | D11 / ICSP | SPI Data Out | 5.0V Logic | Control and initialization commands |
| | SPI MISO | D12 / ICSP | SPI Data In | 5.0V Logic | 60 FPS reading of color blocks and signatures |
| | SPI SCK | D13 / ICSP | SPI Clock | 5.0V Logic | High-speed SPI communication clock |
| **Master Logic Power** | 5V / VIN | 5V | Power In | 5.0V Reg. | 5.0V output from DSN-MINI-360 Buck (Channel 1) |
| | GND | GND | Ground | 0V | Unified ground point |

---

## 2. Pin Mapping - Arduino Nano Slave (Actuators)

The Slave Arduino Nano handles commands sent by the Master via I2C, and controls the servomotor and DC motor.

| Component / Module | Component Pin | Arduino Nano Pin | Signal Type | Voltage Level | Description / Function |
| :--- | :---: | :---: | :---: | :---: | :--- |
| **Steering Servomotor** | Signal (PWM) | D2 | PWM Output | 5.0V Logic | Angle control for Ackermann steering mechanism |
| **L298N H-Bridge Motor Driver (DC Motor)** | IN1 / A1 | D5 | PWM Output | 5.0V Logic | PWM speed modulation for traction motor |
| | IN2 / A2 | D6 | Output | 5.0V Logic | Rotation direction (Set to LOW for forward motion) |
| **I2C Interconnection (Master)** | SDA | A4 (SDA) | I2C Data | 5.0V Logic | Bus for receiving commands from Master Nano |
| | SCL | A5 (SCL) | I2C Clock | 5.0V Logic | Shared I2C bus clock |
| **Slave Logic Power** | 5V / VIN | 5V | Power In | 5.0V Reg. | 5.0V output from DSN-MINI-360 Buck (Channel 2) |
| | GND | GND | Ground | 0V | Unified ground point |

---

## 3. Power System Architecture and Buck Regulators

The primary power source consists of 3 Series Lithium Batteries (3S) delivering a nominal voltage of 11.1V (up to 12.6V fully charged). Power is distributed through two independent step-down converters (DSN-MINI-360 Buck) to isolate dynamic motor current draw from sensitive digital logic.

| Power Stage / Module | Input Source | Regulated Output | Powered Components |
| :--- | :--- | :--- | :--- |
| **Lithium Batteries (3S Series)** | 3x 3.7V Li Battery | 11.1V - 12.6V Direct | VM power input for TB6612FNG Driver (DC Motor) |
| **DSN-MINI-360 Regulator (Channel 1)** | 3S Lithium Pack | 5.0V DC Reg. | Master Arduino Nano, MPU6050 Gyroscope, 3x US-016, and PixyCam2 |
| **DSN-MINI-360 Regulator (Channel 2)** | 3S Lithium Pack | 5.0V DC Reg. | Slave Arduino Nano, Ackermann Servomotor |
| **Common Ground (GND)** | N/A | 0V (GND) | Common physical ground connection for all boards and sensors |

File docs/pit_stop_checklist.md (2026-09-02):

Before releasing Meteoro onto the track, it's worth reviewing these five points in the pits to avoid surprises or unexpected resets mid-race.

**Pre-Track Checklist (Meteoro v2.0)**

| Check | Control Point | Test Method | Acceptance Criteria | Quick Pit Fix |
| :---: | :--- | :--- | :--- | :--- |
| `[ ]` | **1. 3S Battery** | Measure at XT60 connector with multimeter | Voltage **$\ge 11.8\text{ V DC}$** | Swap for a freshly charged battery |
| `[ ]` | **2. Steering Servo** | Power logic and send 90° signal | Wheels aligned to center | Adjust mechanical linkage or trim |
| `[ ]` | **3. Ultrasonic Sensors** | Clean meshes (Front, Left, Right) | Sensors secure and dust-free | Clean with anti-static brush |
| `[ ]` | **4. I2C Bus** | Check physical fit of SDA/SCL wires | Firm connections without play | Re-seat or replace connectors |
| `[ ]` | **5. IMU Calibration** | Power on with car completely stationary | Wait 5 s to set zero reference | Reboot on a flat surface |

---

**Key Points Step-by-Step**

**1. 3S Battery Voltage**
Measure the voltage directly at the XT60 connector before each run. If the reading drops below 11.8 V (less than 3.93 V per cell), any sudden motor acceleration will trigger a voltage drop (*brownout*) and reset the microcontroller mid-race.

**2. Mechanical Servo Centering**
With the electronics powered on and the signal set to 90°, the front wheels should look straight at a glance. If you notice any deviation, adjust the mechanical pushrod or the servo horn before tweaking code. The hardware should leave the pit table properly aligned.

**3. Cleaning Transducers (RCWL-1601)**
Pit area dust accumulates quickly on the metal meshes of the three ultrasonic sensors. Give them a light brushing and check that the mounts aren't loose; a loose or dirty sensor will pick up false echoes off the walls.

**4. I2C Bus Stability**
Chassis vibrations tend to loosen data (SDA) and clock (SCL) lines. Feel the connectors between the Nano boards and the MPU-6050 IMU to ensure a tight fit. If the I2C bus loses connection while running, orientation readings will freeze.

**5. Inertial IMU Calibration**
Place the vehicle on a firm, level surface before turning on the power switch. Once powered up, do not move the car for at least 5 seconds. The gyroscope needs that time in absolute rest to capture its zero reference and ensure precise 72° turns.

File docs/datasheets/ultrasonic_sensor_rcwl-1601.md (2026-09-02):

https://www.manorshi.com/es/RCWL-1601-Ultrasonic-Ranging-Sensor-Module-Digital-Sensor-Module-pd43503559.html

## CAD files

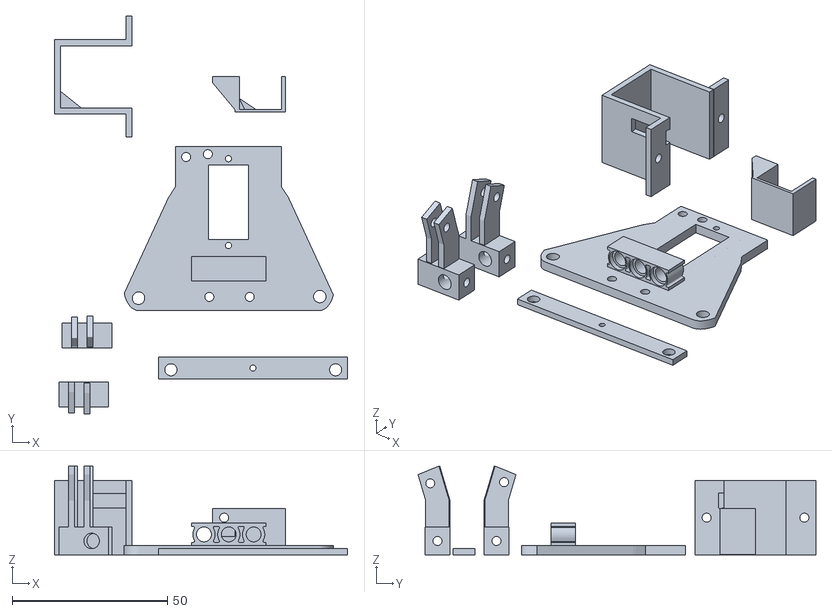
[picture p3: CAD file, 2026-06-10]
models/chassis_pit_dinoco/pit.dinoco_improved.direction.stl
94.5 x 128.3 x 28.6

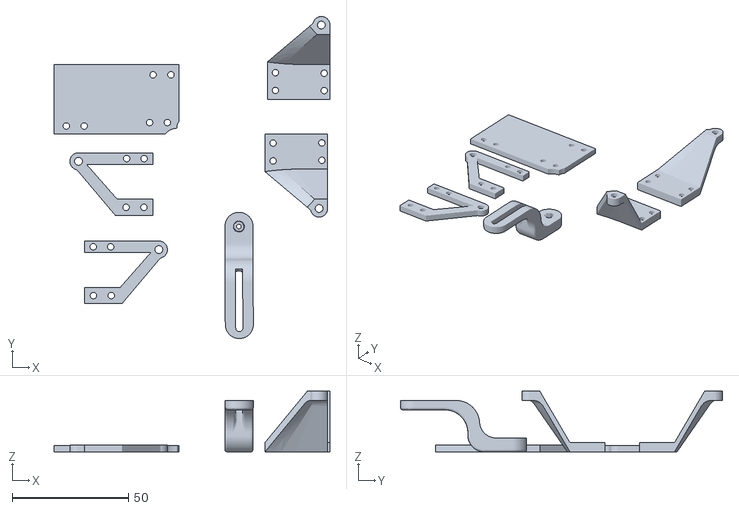
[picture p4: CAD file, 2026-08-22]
models/meteoro_improved.parts.stl
118.8 x 138.7 x 26.2

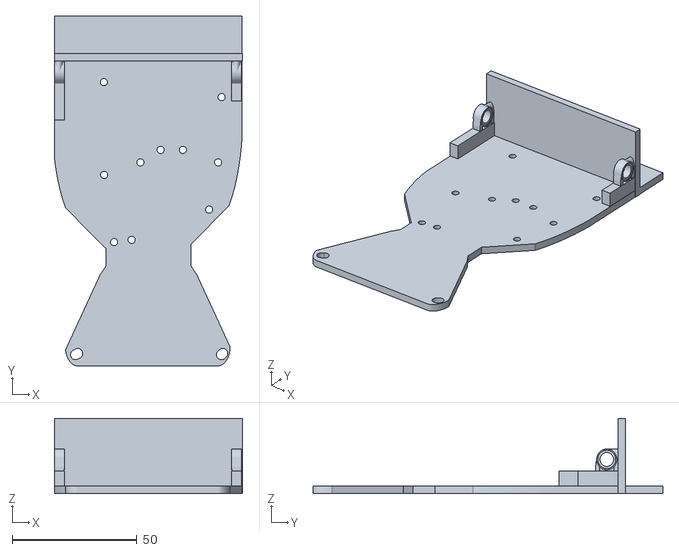
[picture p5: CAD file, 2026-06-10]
models/chassis_pit_dinoco/pit.dinoco_chassis.2.0.stl
75.4 x 140.0 x 30.0

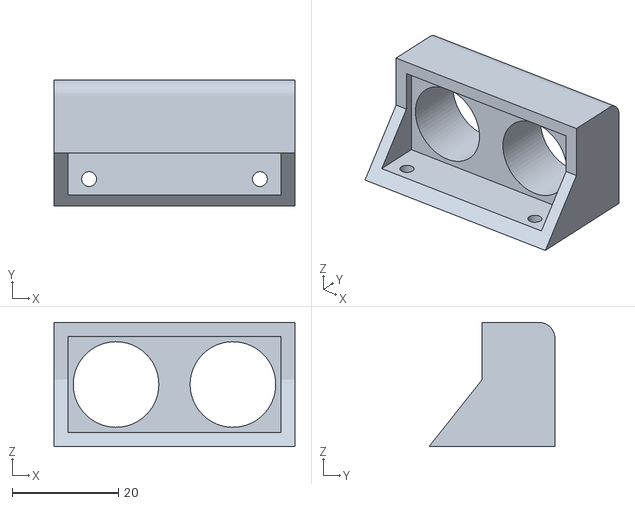
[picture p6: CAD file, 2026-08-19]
models/meteoro_front.sensor.base.stl
45.4 x 23.7 x 23.3

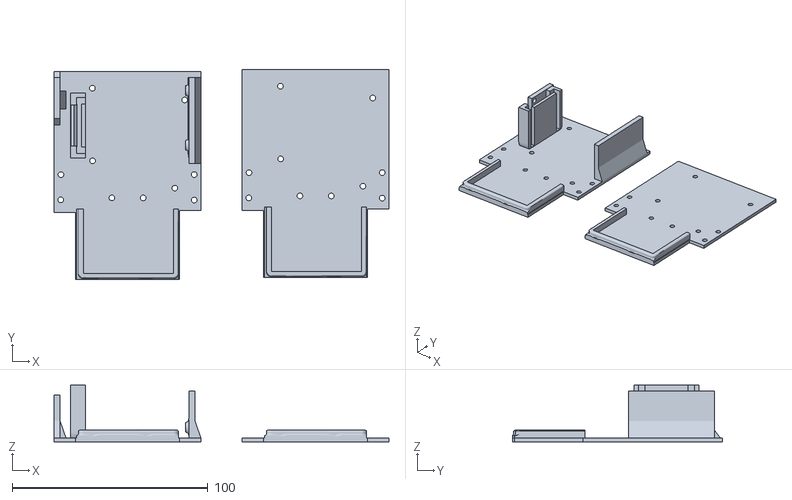
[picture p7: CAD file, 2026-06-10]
models/chassis_pit_dinoco/pit.dinoco_second.floor.2.0.stl
171.0 x 107.0 x 29.0

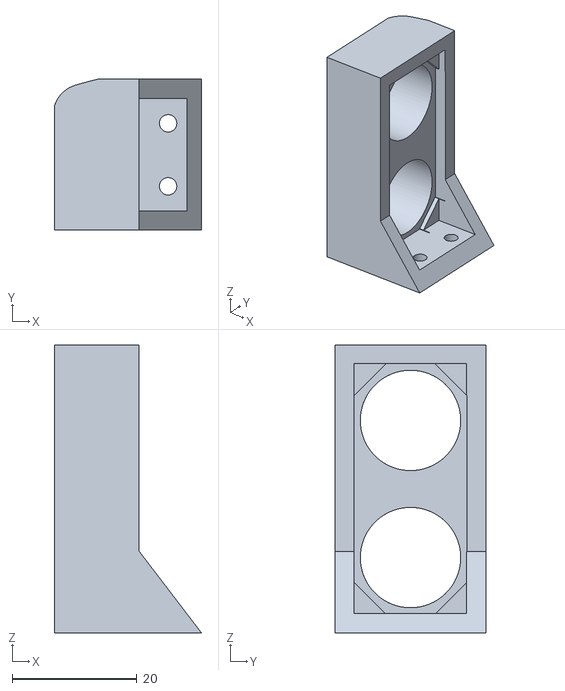
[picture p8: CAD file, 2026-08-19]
models/meteoro_left.sensor.base.stl
23.6 x 24.2 x 46.2

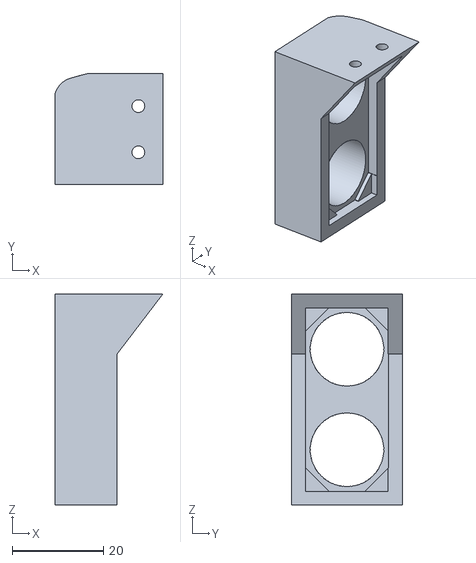
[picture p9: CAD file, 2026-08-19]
models/meteoro_right.sensor.base.stl
23.6 x 24.2 x 46.2

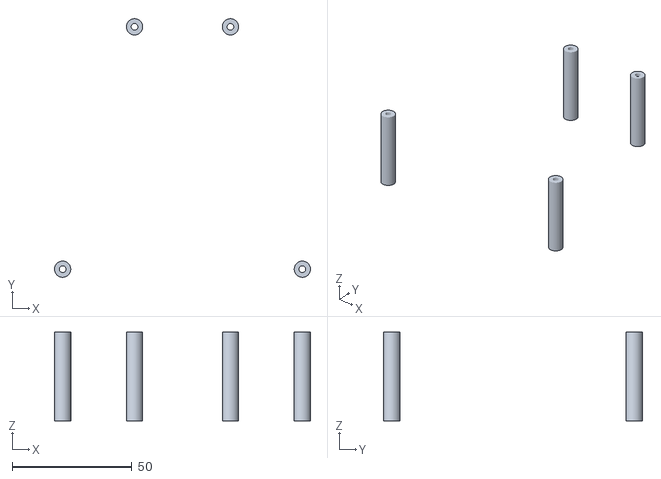
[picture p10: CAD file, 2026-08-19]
models/meteoro_supports.stl
106.8 x 107.9 x 37.0

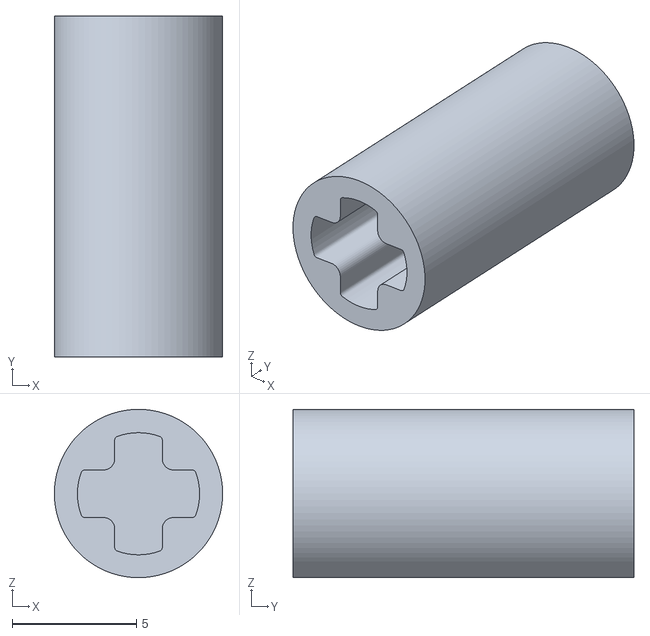
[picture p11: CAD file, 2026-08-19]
models/meteoro_lego.motor.connector.stl
6.78 x 13.7 x 6.78

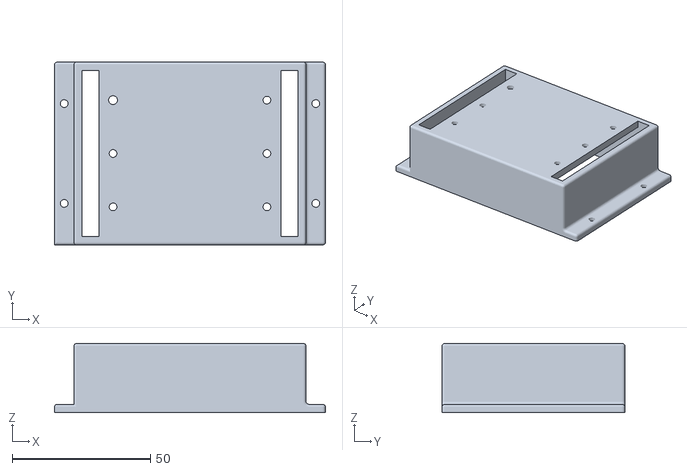
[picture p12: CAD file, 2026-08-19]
models/meteoro_battery.compartment.base.stl
97.9 x 66.1 x 25.0

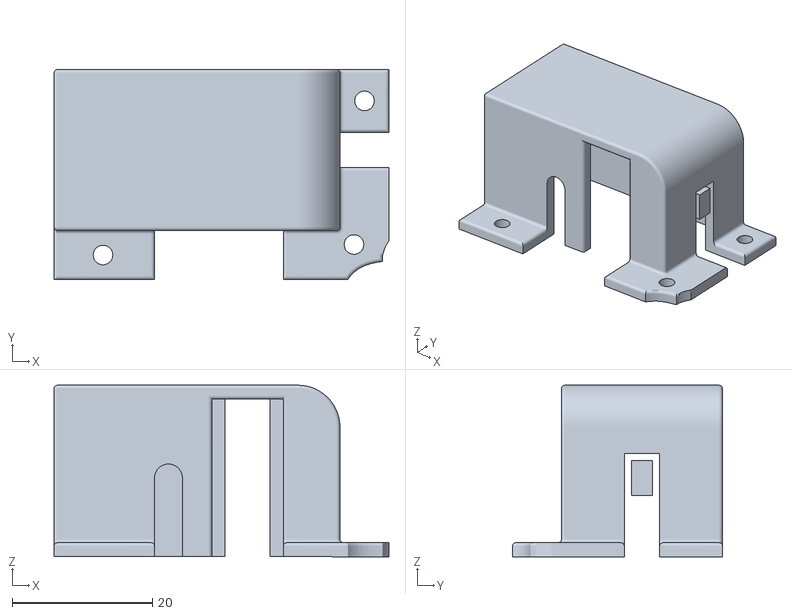
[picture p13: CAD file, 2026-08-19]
models/meteoro_motor.base.stl
47.8 x 30.0 x 24.5

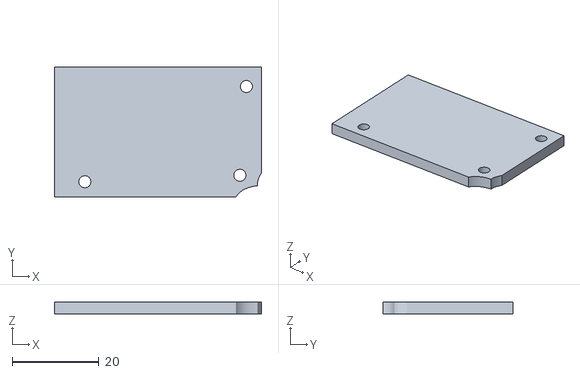
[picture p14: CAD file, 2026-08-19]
models/meteoro_bottom.motor.base.stl
47.9 x 30.0 x 2.78

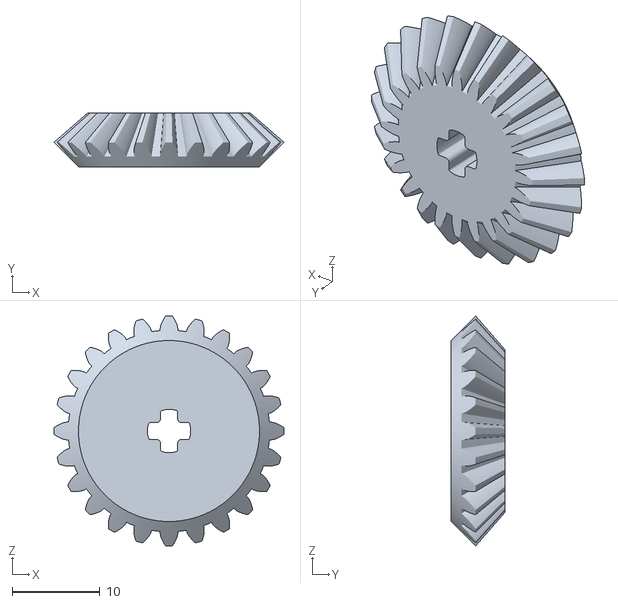
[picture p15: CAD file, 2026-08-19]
models/gear24T.stl
26.2 x 6.11 x 26.2

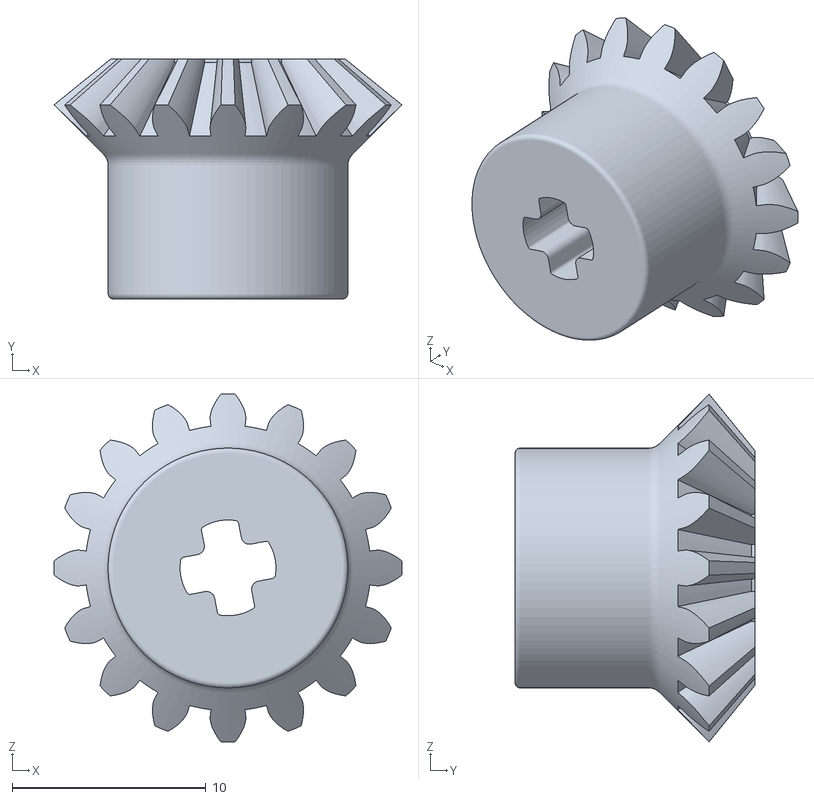
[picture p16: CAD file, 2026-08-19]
models/gear16T.modified.stl
18.0 x 12.4 x 18.0

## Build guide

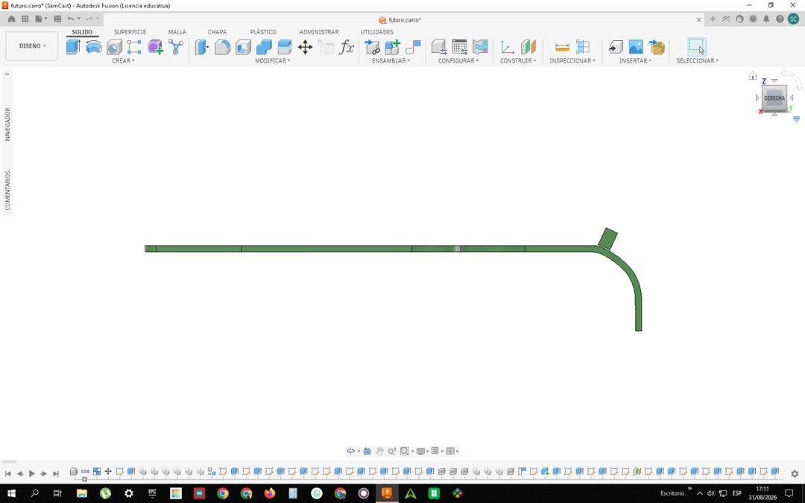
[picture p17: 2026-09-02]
photos/assembly_process/WhatsApp Image 2026-09-02 at 2.10.28 AM (2).jpeg

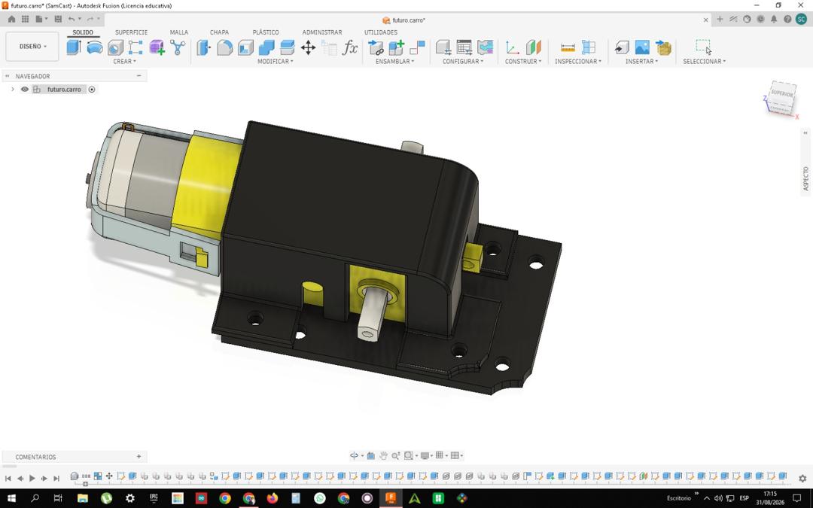
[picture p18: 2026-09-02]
photos/assembly_process/WhatsApp Image 2026-09-02 at 2.10.49 AM.jpeg

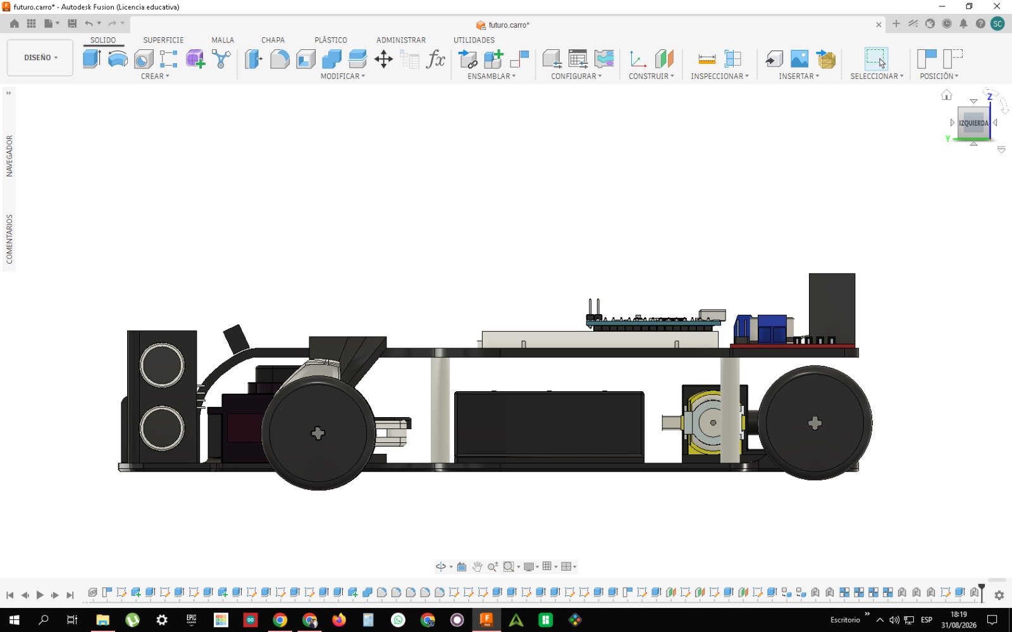
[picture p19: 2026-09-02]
photos/assembly_process/WhatsApp Image 2026-09-02 at 2.11.09 AM.jpeg

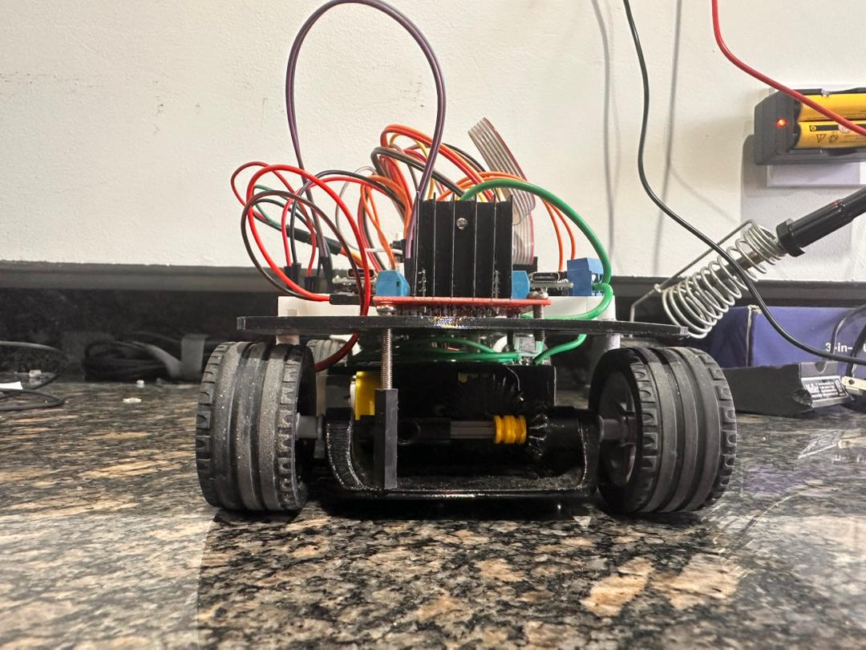
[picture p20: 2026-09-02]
photos/assembly_process/WhatsApp Image 2026-09-02 at 2.08.40 AM.jpeg

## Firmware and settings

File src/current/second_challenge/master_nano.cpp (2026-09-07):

#include <Arduino.h>
#include <Wire.h>
#include <NewPing.h>
#include <Pixy2.h>

#define DIRECCION_ESCLAVO 0x08
#define MPU6050_ADDR 0x68
 
// --- PINES DEL BOTÓN DE INICIO ---
#define PIN_BTN_OUT 3
#define PIN_BTN_IN  2

// --- PINES DE SENSORES ULTRASÓNICOS ---
#define MAX_DISTANCE 200
#define TRIG_FRONT 10
#define ECHO_FRONT 9
#define TRIG_DER 8
#define ECHO_DER 7
#define TRIG_IZQ 6
#define ECHO_IZQ 5

NewPing sensorIzq(TRIG_IZQ, ECHO_IZQ, MAX_DISTANCE);
NewPing sensorDer(TRIG_DER, ECHO_DER, MAX_DISTANCE);
NewPing sensorFront(TRIG_FRONT, ECHO_FRONT, MAX_DISTANCE);

// --- PIXYCAM 2 ---
Pixy2 pixy;
const int FIRMA_VERDE = 1; // Pasa por la IZQUIERDA
const int FIRMA_ROJA  = 2; // Pasa por la DERECHA

const int ALTO_MIN_CERCA = 60;  
const int ALTO_MAX_CERCA = 220;

// --- CONFIGURACIÓN DE VELOCIDADES ---
const int VEL_RECTA = 120;   // Velocidad rápida para ir recto
const int VEL_ESQUIVE = 120; // Velocidad reducida para maniobras
const int VEL_CURVA = 120;   // Velocidad para tomar la curva de forma rápida
const int VEL_REVERSA = -100;

// --- CONSTANTES DEL PD Y SENSORES ---
float Kp = 10;  
float Kd = 3;
float error_anterior = 0;  

float distIzqFiltrada = 30.0;
float distDerFiltrada = 30.0;
float distFrontFiltrada = 120.0; // Añadido para la curva

// --- FILTRO ANTI-FALSOS POSITIVOS (DEBOUNCE) ---
int lecturasVerdeConsecutivas = 0;
int lecturasRojaConsecutivas = 0;
const int UMBRAL_CONFIRMACION = 3;

// --- MÁQUINA DE ESQUIVE Y CURVAS ---
enum EstadoEsquive {
  RECTA_NORMAL,
  ESQUIVANDO_IZQ, REBASANDO_IZQ, ENDEREZANDO_IZQ,
  ESQUIVANDO_DER, REBASANDO_DER, ENDEREZANDO_DER,
  GIRANDO_CURVA, COOLDOWN_CURVA, RETROCESO_EMERGENCIA, DETENIDO // NUEVOS ESTADOS DE CURVA
};
EstadoEsquive estadoEsquive = RECTA_NORMAL;

unsigned long tiempoInicioRetroceso = 0;
const unsigned long TIEMPO_RETROCESO_MS = 450;

unsigned long tiempoInicioRebase = 0;
unsigned long tiempoInicioEnderezado = 0;

// PARÁMETROS DE TIEMPO Y SEGURIDAD (ESQUIVE)
const unsigned long TIEMPO_REBASE_MS = 600;        
const unsigned long TIEMPO_MAX_ENDEREZANDO_MS = 200;
const float ANGULO_OBJETIVO_ESQUIVE = 10.0;

// --- PARÁMETROS DE CURVA ---
// --- NUEVO: COOLDOWN DE SENSORES (TIEMPO CIEGO) ---
const unsigned long TIEMPO_CIEGO_SENSORES = 500; // Milisegundos ignorando paredes al salir de curva
const float DIST_DETECCION_CURVA = 65.0;
const float ANGULO_OBJETIVO_CURVA = 65.0;
int direccionGiroCurva = 90;
unsigned long tiempoInicioCooldownCurva = 0;
const unsigned long TIEMPO_COOLDOWN_CURVA = 500;
unsigned long ultimoTiempoCurva = 0;
const unsigned long FRONT_COOLDOWN_CURVA = 2500; // Evita que doble dos veces seguidas

unsigned long ultimoTiempoBloque = 0; // Memoria de la cámara
const unsigned long MEMORIA_PIXY_MS = 1000; // 1 segundo de bloqueo de curva

int confirmacionCurva = 0;
const int UMBRAL_CURVA = 2; // Exige ver la pared 2 veces seguidas antes de girar

int contadorCurvas = 0;
const int TOTAL_CURVAS = 12; // 3 vueltas * 4 esquinas = 12 curvas

// --- GIROSCOPIO ---
float anguloZ_acumulado = 0.0;
float offsetZ = 0.0;
unsigned long tiempo_anterior = 0;
bool giroFuePositivo = true;

float leerGiroscopioZ();
float filtrarLectura(float lecturaCruda, float lecturaAnterior);
void enviarComandosEsclavo(int angulo, int velocidad);

void setup() {
  pinMode(PIN_BTN_OUT, OUTPUT);
  digitalWrite(PIN_BTN_OUT, HIGH);
  pinMode(PIN_BTN_IN, INPUT);

  Wire.begin();
  pixy.init();
  pixy.setLamp(1, 0);

  Wire.beginTransmission(MPU6050_ADDR);
  Wire.write(0x6B);
  Wire.write(0);    
  Wire.endTransmission(true);

  long sumaZ = 0;
  for(int i = 0; i < 50; i++) {
    sumaZ += leerGiroscopioZ();
    delay(3);
  }
  offsetZ = sumaZ / 50.0;

  while (digitalRead(PIN_BTN_IN) == LOW) {
    delay(20);
  }

  ultimoTiempoBloque = millis(); 
  tiempo_anterior = micros();
}

void loop() {
  // 1. LECTURA Y CÁLCULO DEL GIROSCOPIO
  unsigned long tiempoActualMicros = micros();
  float dt = (float)(tiempoActualMicros - tiempo_anterior) / 1000000.0;
  if (dt <= 0) dt = 0.001;
 
  float giroZ = (leerGiroscopioZ() - offsetZ) / 131.0;

  if (estadoEsquive != RECTA_NORMAL) {
    anguloZ_acumulado += (giroZ * dt);
  }

  // 2. LECTURA Y VALIDACIÓN CONTINUA DE PIXYCAM
  int posXVerde = 0;
  int posXRoja = 0;
  bool verdeEnFrame = false;
  bool rojaEnFrame = false;

  pixy.ccc.getBlocks();
  if (pixy.ccc.numBlocks) {
    for (int i = 0; i < pixy.ccc.numBlocks; i++) {
      int h = pixy.ccc.blocks[i].m_height;
      if (h >= ALTO_MIN_CERCA && h <= ALTO_MAX_CERCA) {
        if ((pixy.ccc.blocks[i].m_signature == 1 || pixy.ccc.blocks[i].m_signature == 3) && !verdeEnFrame) {
          posXVerde = pixy.ccc.blocks[i].m_x;
          verdeEnFrame = true;
        }
        else if (pixy.ccc.blocks[i].m_signature == FIRMA_ROJA && !rojaEnFrame) {
          posXRoja = pixy.ccc.blocks[i].m_x;
          rojaEnFrame = true;
        }
      }
    }
  }

  if (verdeEnFrame) {
    lecturasVerdeConsecutivas++;
    lecturasRojaConsecutivas = 0;
  } else if (rojaEnFrame) {
    lecturasRojaConsecutivas++;
    lecturasVerdeConsecutivas = 0;
  } else {
    lecturasVerdeConsecutivas = 0;
    lecturasRojaConsecutivas = 0;
  }

  bool verdeConfirmado = (lecturasVerdeConsecutivas >= UMBRAL_CONFIRMACION);
  bool rojaConfirmada  = (lecturasRojaConsecutivas >= UMBRAL_CONFIRMACION);
  bool bloqueCerca = (verdeEnFrame || rojaEnFrame); // Indicador general de objeto

  // 3. LÓGICA DE MOVIMIENTO PROTEGIDA
  int anguloDestino = 90;

  // SELECCIÓN AUTOMÁTICA DE VELOCIDAD SEGÚN EL ESTADO
  int velocidadActual = VEL_ESQUIVE;
  if (estadoEsquive == RECTA_NORMAL) velocidadActual = VEL_RECTA;
  else if (estadoEsquive == GIRANDO_CURVA) velocidadActual = VEL_CURVA;
  else if (estadoEsquive == DETENIDO) velocidadActual = 0; // Apaga los motores
  else if (estadoEsquive == RETROCESO_EMERGENCIA) velocidadActual = VEL_REVERSA; // NUEVO

  switch (estadoEsquive) {
    case RECTA_NORMAL:
      
      if (contadorCurvas >= TOTAL_CURVAS) {
        estadoEsquive = DETENIDO;
        break; 
      }

      // --- LECTURA RÁPIDA DE EMERGENCIA ---
      float rawEmergencia = sensorFront.ping_cm();
      if (rawEmergencia > 0 && rawEmergencia <= 12.0) {
         distFrontFiltrada = rawEmergencia; 
      } else if (rawEmergencia == 0.0) {
         distFrontFiltrada = 3.0; // Si da 0, choca.
      }

      // 1. PRIORIDAD MÁXIMA: Detección de peligro inminente (Ultrasonido)
      if (distFrontFiltrada <= 8.0) {
        estadoEsquive = RETROCESO_EMERGENCIA;
        tiempoInicioRetroceso = millis();
        break; // IMPORTANTE: El break evita que ejecute el resto del código
      }

      // 2. PRIORIDAD MEDIA: Esquive de bloques Pixy
      if (verdeConfirmado) {
        estadoEsquive = ESQUIVANDO_IZQ;
        anguloZ_acumulado = 0.0;
      }
      else if (rojaConfirmada) {
        estadoEsquive = ESQUIVANDO_DER;
        anguloZ_acumulado = 0.0;
      }
      else {
        // 2. COOLDOWN DE PAREDES: ¿Acabamos de salir de una curva?
        if (millis() - ultimoTiempoCurva < TIEMPO_CIEGO_SENSORES) {
            // Ignoramos ultrasonidos y PID. Mantenemos el volante recto.
            anguloDestino = 90;
            error_anterior = 0; // Reseteamos el PID para no arrastrar basura
            
            // Forzamos las variables filtradas a valores neutros
            distIzqFiltrada = 30.0;
            distDerFiltrada = 30.0;
            distFrontFiltrada = 120.0;
        } 
        // 3. SENSORES ACTIVOS: Si ya pasó el cooldown, leemos paredes y hacemos PID
        else {
            // Lectura de los 3 sensores
            float rawIzq = sensorIzq.ping_cm();
            distIzqFiltrada = filtrarLectura(rawIzq, distIzqFiltrada);
            delay(15);
           
            float rawDer = sensorDer.ping_cm();
            distDerFiltrada = filtrarLectura(rawDer, distDerFiltrada);
            delay(15);

            float rawFront = sensorFront.ping_cm();
            distFrontFiltrada = filtrarLectura(rawFront, distFrontFiltrada);
            delay(15);

            bool posibleObstaculo = (millis() - ultimoTiempoBloque < MEMORIA_PIXY_MS);
            bool huecoIzquierda = (distIzqFiltrada > 90.0);
            bool huecoDerecha = (distDerFiltrada > 90.0);

            // Detección de nueva curva
            if (distFrontFiltrada <= 70.0 && distFrontFiltrada > 30.0 && (huecoIzquierda || huecoDerecha) &&
                !posibleObstaculo) {
               
                confirmacionCurva++;
                if (confirmacionCurva >= UMBRAL_CURVA) {
                    estadoEsquive = GIRANDO_CURVA; 
                    anguloZ_acumulado = 0.0;
                    confirmacionCurva = 0; 
                   
                    if (huecoIzquierda) direccionGiroCurva = 35; // Hueco Izq -> Gira Izq
                    else direccionGiroCurva = 145;                 // Hueco Der -> Gira Der
                }
            }
            // Control PID de carril
            else {
              confirmacionCurva = 0; 
              
              float distancia_al_centro = (distDerFiltrada - distIzqFiltrada) / 2.0;
              float error = 0;
              float limitePID = 17.0;

              const float ZONA_AZUL = 4.0;
              if (abs(distancia_al_centro) <= ZONA_AZUL) error = 0;
              else {
                if (distancia_al_centro > 0) error = distancia_al_centro - ZONA_AZUL;
                else error = distancia_al_centro + ZONA_AZUL;
              }

              float P = Kp * error;
              float tasa_cambio = (error - error_anterior) / dt;
              tasa_cambio = constrain(tasa_cambio, -150.0, 150.0);
              float D = Kd * tasa_cambio;
             
              float salidaPID = constrain(P + D, -limitePID, limitePID);
             
              anguloDestino = 90 + salidaPID;
              anguloDestino = constrain(anguloDestino, 45, 135);
             
              error_anterior = error;
            }
        }
      }
      break;

    // --- NUEVO: MANIOBRA DE CURVA ---
    case GIRANDO_CURVA:
      anguloDestino = direccionGiroCurva; // Ángulo máximo físico de dirección
     
      // Monitorea el giroscopio para saber cuándo completó los ~76 grados de la curva
      if (abs(anguloZ_acumulado) >= ANGULO_OBJETIVO_CURVA) {
        estadoEsquive = COOLDOWN_CURVA;
        tiempoInicioCooldownCurva = millis();
        error_anterior = 0;
        contadorCurvas++;
      }
      delay(1000);
      break;

    case COOLDOWN_CURVA:
      anguloDestino = 90; // Mantiene el volante recto al salir de la curva
      if (millis() - tiempoInicioCooldownCurva > TIEMPO_COOLDOWN_CURVA) {
        estadoEsquive = RECTA_NORMAL;
        ultimoTiempoCurva = millis(); // Inicia el bloqueo para no detectar la misma pared
      }
      break;

    // --- MANIOBRA VERDE (ESQUIVE POR IZQUIERDA) ---
    case ESQUIVANDO_IZQ:
      anguloDestino = 145;
      if (anguloZ_acumulado >= ANGULO_OBJETIVO_ESQUIVE && (verdeEnFrame && posXVerde >= 200)) {
        estadoEsquive = REBASANDO_IZQ;
        tiempoInicioRebase = millis();
      }
      else if (!verdeEnFrame && anguloZ_acumulado < (ANGULO_OBJETIVO_ESQUIVE * 0.4)) {
        estadoEsquive = RECTA_NORMAL;
      }
      break;

    case REBASANDO_IZQ:
      anguloDestino = 90;
      if (millis() - tiempoInicioRebase >= TIEMPO_REBASE_MS) {
        estadoEsquive = ENDEREZANDO_IZQ;
        tiempoInicioEnderezado = millis();
        giroFuePositivo = (anguloZ_acumulado > 0);
      }
      break;

    case ENDEREZANDO_IZQ:
      anguloDestino = 35;
      if ((giroFuePositivo ? (anguloZ_acumulado <= 0.0) : (anguloZ_acumulado >= 0.0)) ||
          (millis() - tiempoInicioEnderezado >= TIEMPO_MAX_ENDEREZANDO_MS)) {
        estadoEsquive = RECTA_NORMAL;
        error_anterior = 0;
      }
      break;

    // --- MANIOBRA ROJA (ESQUIVE POR DERECHA) ---
    case ESQUIVANDO_DER:
      anguloDestino = 35;
      if (anguloZ_acumulado <= -ANGULO_OBJETIVO_ESQUIVE && (rojaEnFrame && posXRoja <= 40)) {
        estadoEsquive = REBASANDO_DER;
        tiempoInicioRebase = millis();
      }
      else if (!rojaEnFrame && anguloZ_acumulado > (-ANGULO_OBJETIVO_ESQUIVE * 0.4)) {
        estadoEsquive = RECTA_NORMAL;
      }
      break;

    case REBASANDO_DER:
      anguloDestino = 90;
      if (millis() - tiempoInicioRebase >= TIEMPO_REBASE_MS) {
        estadoEsquive = ENDEREZANDO_DER;
        tiempoInicioEnderezado = millis();
        giroFuePositivo = (anguloZ_acumulado > 0);
      }
      break;

    case ENDEREZANDO_DER:
      anguloDestino = 135;
      if ((giroFuePositivo ? (anguloZ_acumulado <= 0.0) : (anguloZ_acumulado >= 0.0)) ||
          (millis() - tiempoInicioEnderezado >= TIEMPO_MAX_ENDEREZANDO_MS)) {
        estadoEsquive = RECTA_NORMAL;
        error_anterior = 0;
      }
      break;

    case DETENIDO:
      anguloDestino = 90; // Endereza las ruedas
      break;

    case RETROCESO_EMERGENCIA:
    anguloDestino = 90; // Mantiene el volante recto mientras retrocede
    
    // Retrocede durante el tiempo definido (TIEMPO_RETROCESO_MS, actualmente 450ms)
    if (millis() - tiempoInicioRetroceso >= TIEMPO_RETROCESO_MS) {
      estadoEsquive = RECTA_NORMAL;
      // Limpiamos los contadores para que no vuelva a retroceder de inmediato con basura de memoria
      lecturasVerdeConsecutivas = 0; 
      lecturasRojaConsecutivas = 0;
      ultimoTiempoBloque = millis(); 
    }
    break;
  }

  // 4. ENVÍO DE DATOS
  enviarComandosEsclavo(anguloDestino, velocidadActual);
  tiempo_anterior = tiempoActualMicros;
}

void enviarComandosEsclavo(int angulo, int velocidad) {
  Wire.beginTransmission(DIRECCION_ESCLAVO);
  Wire.write((byte)angulo);                  
  Wire.write((int8_t)velocidad); 
  Wire.endTransmission();                    
}

float leerGiroscopioZ() {
  Wire.beginTransmission(MPU6050_ADDR);
  Wire.write(0x47);
  Wire.endTransmission(false);
  Wire.requestFrom(MPU6050_ADDR, 2, true);
 
  if (Wire.available() >= 2) {
    int16_t Z = Wire.read() << 8 | Wire.read();
    return (float)Z;
  }
  return 0.0;
}

float filtrarLectura(float lecturaCruda, float lecturaAnterior) {
  if (lecturaCruda == 0.0) {
    lecturaCruda = 200.0; // Forzamos la lectura a la distancia máxima real
  } else if (lecturaCruda <= 2.0) {
    return lecturaAnterior; // Ignoramos solo el ruido por contacto físico o cableado
  }
  
  float alpha = 0.4;
  return (alpha * lecturaCruda) + ((1.0 - alpha) * lecturaAnterior);
}

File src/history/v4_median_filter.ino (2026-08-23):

#include <Servo.h>

//Ohhh Servo mi Servo
Servo miServo;

//Ultrasónicos
const int trigIzq = 9, echoIzq = 10;
const int trigDer = 3, echoDer = 2;
const int trigFront = 7, echoFront = 8;

//Se viven quemando
const int in1 = 6;  
const int in2 = 5;

//Constantes del PID
float Kp = 7.0;
float Kd = 10.0;
float Ki = 0.001;

//Variables del PID
float error_anterior = 0;
unsigned long tiempo_anterior = 0;
float suma_errores = 0;
const float LIMITE = 1000.0;

//Rapido y Lento
const int velMax = 255;  
const int velMin = 170;  // Subido a 195 como pediste para la curva agresiva

//Pa que de 3 vueltas
int girosRealizados = 0;
const int giros_max = 12;
bool misionTerminada = false;

//Estados del carrito
const int Inicio = 0;
const int PID = 1;
const int Girando = 2;

int estadoActual = Inicio;

// 'U'=Nosabe, 'I'=Izq, 'D'=Der
char direccionBloqueada = 'U';    
   
const float distanciaLim = 130.0;
const float distanciaHueco = 90.0;

// Memoria para la función tomarEsquinaGradual
int anguloActualInterno = 90;        

// Arreglos globales pal filtro contra el ruido
float historialIzq[4] = {150.0, 150.0, 150.0, 150.0};
float historialDer[4] = {150.0, 150.0, 150.0, 150.0};
float historialFront[4] = {150.0, 150.0, 150.0, 150.0};

void setup() {
  Serial.begin(115200);

  pinMode(trigIzq, OUTPUT); pinMode(echoIzq, INPUT);
  pinMode(trigDer, OUTPUT); pinMode(echoDer, INPUT);
  pinMode(trigFront, OUTPUT); pinMode(echoFront, INPUT);
   pinMode(in1, OUTPUT); pinMode(in2, OUTPUT);

  miServo.attach(11);
  miServo.write(90);

  Serial.println("Si doy tres vueltas guillermo compra una torta");
 
  // Ya entendí el for
  
  Serial.println("Acelerando misil...");
  for (int v = 0; v <= velMax; v += 5) {
    avanzar(v);
    delay(35);
  }
 
  tiempo_anterior = millis();
}

void loop() {
 
  //El ganador ps
  if (misionTerminada == true) {
    digitalWrite(in1, LOW);
    digitalWrite(in2, LOW);
    miServo.write(90);
    while (true) {}
  }

  //Ultrasónicos joseando (ahora con filtro de proteccion)
  float distFront = filtroMediana4(medirDistancia(trigFront, echoFront), historialFront);
  float distIzq = filtroMediana4(medirDistancia(trigIzq, echoIzq), historialIzq);
  float distDer = filtroMediana4(medirDistancia(trigDer, echoDer), historialDer);
  
  //Migración Interna (Cambio de estado)
  switch (estadoActual) {

    case Inicio:
      //Avanza hasta que se encuentre algo
      avanzar(velMax);
      float distFront;
      float distIzq;
      float distDer;
      miServo.write(90);

      if (distFront <= distanciaLim) {
        //Elige pa donde va
        Serial.println("VOY PALAO - Tomando decision permanente");
        if (distIzq > distDer) {
          direccionBloqueada = 'I';
          Serial.println("-> Direccion bloqueada: IZQUIERDA");
        }
        else {
          direccionBloqueada = 'D';
          Serial.println("-> Direccion bloqueada: DERECHA");
        }
        estadoActual = Girando;
      }
      break;

    case PID:
      //Usamos PID porque yo no me maté toda una madrugada pa un coño
      ejecutarControlPID(distIzq, distDer);

      // --- NUEVA LÓGICA DE DETECCIÓN DE HUECOS ---
      // Si la dirección bloqueada es Izquierda y de repente hay un espacio grande a la izquierda
      if (direccionBloqueada == 'I' && distIzq >= distanciaHueco) {
        Serial.println("¡Hueco a la izquierda detectado! Entrando a curva...");
        estadoActual = Girando;
      }
      // Si la dirección bloqueada es Derecha y de repente hay un espacio grande a la derecha
      else if (direccionBloqueada == 'D' && distDer >= distanciaHueco) {
        Serial.println("¡Hueco a la derecha detectado! Entrando a curva...");
        estadoActual = Girando;
      }
      
      // Seguridad opcional: por si acaso el carro entra cruzado y no lee bien el hueco
      else if (distFront <= 40.0) { 
        estadoActual = Girando;
      }
      break;

    case Girando:
      //Giramos (NI MODO QUE VAYA PA ATRAS, SI DICE LA VARIABLE GIRANDO NO VA A SER PORQUE VA A VOLAR)
      ejecutarGiroMecanico();
      break;
  }
  Serial.print("frontal: ");
  Serial.println(distFront);
  Serial.print("izquierda: ");
  Serial.println(distIzq);
  Serial.print("derecha: ");
  Serial.println(distDer);
}

//PID como función pa mantener el orden muchachos
void ejecutarControlPID(float distIzq, float distDer) {

  //Taima (dt)
  unsigned long tiempoActual = millis();
  float dt = (float)(tiempoActual - tiempo_anterior);
  if (dt == 0) dt = 1.0;

  //Error
  float error = distIzq - distDer;

  //Me fume uno viendome 5 videos de esto :(
 
  //Dame la P
  float P = Kp * error;
 
  //Dame la I (Se limita para evitar que de vueltas como trompo)
  suma_errores = suma_errores + (error * dt);
  if (suma_errores > LIMITE) suma_errores = LIMITE;
  else if (suma_errores < -LIMITE) suma_errores = -LIMITE;
  float I = Ki * suma_errores;

  //Dame la D
  float tasa_cambio = (error - error_anterior) / dt;
  float D = Kd * tasa_cambio;
 
  //Que diceeeee: PID :)
  float Salida_PID = P + I + D;
 
  //Se aplica al servo
  int anguloDestino = 90 + Salida_PID;
  anguloDestino = constrain(anguloDestino, 45, 135);
  miServo.write(anguloDestino);
  anguloActualInterno = anguloDestino; // Sincronizamos la memoria del volante

  //Memoria
  error_anterior = error;
  tiempo_anterior = tiempoActual;

  //Velocidad Adaptiva con Limite de Curva
  float magnitudGiro = abs(anguloDestino - 90);
  int velocidadAdaptativa = map(magnitudGiro, 0, 45, velMax, velMin);
  velocidadAdaptativa = constrain(velocidadAdaptativa, velMin, velMax);
  avanzar(velocidadAdaptativa);
  float distFront;
  delay(30);
}

//Funcion pa girar
void ejecutarGiroMecanico() {

  Serial.println("Ejecutando curva de carreras...");

  //Frena primero
  for (int v = velMax; v >= velMin; v -= 5) {
    avanzar(v);
    delay(25);
  }

  //Gira hacia el lado bloqueao
  int anguloGiro = (direccionBloqueada == 'I') ? 135 : 45;
  tomarEsquinaGradual(anguloGiro);
  delay(2500);

  //Regresa a 90
  tomarEsquinaGradual(90);

  //Acelera
  for (int v = velMin; v <= velMax; v += 5) {
    avanzar(v);
    delay(25);
  }

  //Conteo de vueltas
  girosRealizados++;
  Serial.print("Una menos. Giros totales: ");
  Serial.print(girosRealizados);
  Serial.print(" / ");
  Serial.println(giros_max);

  if (girosRealizados >= giros_max) {
    Serial.println("Di tres vueltas valeeee");
    misionTerminada = true;
  } 
  else {
    suma_errores = 0;
    error_anterior = 0;
    tiempo_anterior = millis();
    estadoActual = PID;
  }


  //Reinicio de PID
  suma_errores = 0;
  error_anterior = 0;
  tiempo_anterior = millis(); // Reseteamos el reloj
 
  estadoActual = PID; // Devolvemos el cerebro a la matemática
}
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

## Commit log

2026-04-25 Create Arduino Uno Specs.PDF
2026-08-18 Eliminar chassis_pit.dinoco
2026-08-18 Create chassis v2
2026-08-18 Create Chassis v1
2026-08-21 Create chassis_pit_dinoco

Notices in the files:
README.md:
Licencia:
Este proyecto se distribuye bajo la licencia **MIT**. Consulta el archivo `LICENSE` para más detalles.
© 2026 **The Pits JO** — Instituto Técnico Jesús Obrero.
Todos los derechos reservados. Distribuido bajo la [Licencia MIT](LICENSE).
